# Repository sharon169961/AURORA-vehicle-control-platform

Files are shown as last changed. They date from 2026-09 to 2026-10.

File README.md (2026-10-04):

# AURORA — Autonomous Vehicle Control & Power Platform

**4-Layer Mixed-Signal PCB | TI MSPM0G3507 | DRV8323S BLDC FOC | CAN-FD | Power Management**

> Status: **Rev A** — schematic design complete, PCB layout in progress. Built in KiCad 10.



---

## Overview

AURORA is the electronics core for an autonomous ground/underwater vehicle — a single 4-layer PCB integrating power conversion, motor control, sensing, and vehicle networking. The board takes a wide-range 18–36V input and regulates it down through three cascaded stages to power an 80MHz Arm Cortex-M0+ MCU, a 3-phase BLDC gate driver with integrated current sensing, a CAN-FD vehicle network node, and a protected analog sensor front end.

This project was designed module-by-module with every component value backed by a real datasheet calculation — no placeholder values, no guessed passives.

## System Architecture

```
18–36V INPUT
      │
 [Reverse-Polarity + Transient Protection]   (LM74701-Q1, TVS-less ideal diode)
      │
      ▼
 [36V → 12V Buck]  (LM5164, synchronous, 300kHz)
      │
      ▼
 [12V → 5V Buck]   (TPS5430, 500kHz)
      │
      ▼
 [5V → 3.3V LDO]   (TLV75733)
      │
      ├──────────────┬──────────────┬──────────────┐
      ▼              ▼              ▼              ▼
   MCU CORE      ANALOG FE      CAN-FD NODE     MOTOR STAGE
 MSPM0G3507    3-ch protected   TCAN1043      DRV8323S +
 80MHz M0+     RC anti-alias   transceiver    3-phase gate
 CAN/SPI/I2C   ADC front end    120Ω term.    drive + Kelvin-
 /UART hub                                    sense shunts
```

## Key Design Decisions

- **Power tree sized from real calculations** — inductor values, feedback dividers, UVLO thresholds, and compensation networks are all calculated from TI's own design equations, not copied defaults
- **DRV8323S current sensing uses 4-pin Kelvin-sense shunts** (5mΩ, 1%) rather than 2-terminal resistors — eliminates trace/joint resistance error on the high-gain (up to 40V/V) current-sense path
- **Hardware-level motor kill switch** — a physical E-stop directly shorts the gate driver's ENABLE pin to ground, overriding any MCU/firmware state
- **TVS-less input protection** — LM74701-Q1's integrated VDS clamp meets automotive transient requirements without a discrete TVS diode
- **Reverse-polarity protection via ideal diode controller**, not a passive series diode — avoids the forward-voltage power loss of a traditional diode-OR input stage

## Schematic Highlights

| Motor Drive Stage | Power Tree | MCU Core |
|---|---|---|
| || |
| DRV8323S SPI gate driver, 6x PWM, Kelvin-sense current monitoring | 36V → 12V → 5V → 3.3V cascaded regulation, TVS-less input protection | MSPM0G3507 hub — CAN-FD, SPI, I2C, UART, SWD, 3-ch ADC |

Full schematic (all 6 sheets): [`docs/schematic-full.pdf`](docs/schematic-full.pdf)

## Tech Stack

| Domain | Parts |
|---|---|
| MCU | TI MSPM0G3507 (Arm Cortex-M0+, 80MHz, 128KB/32KB, CAN-FD, dual 12-bit ADC) |
| Motor control | TI DRV8323S (SPI-configured 3-phase gate driver, integrated current-shunt amps) |
| Power | TI LM5164, TPS5430, TLV75733, LM74701-Q1 |
| Networking | TI TCAN1043 (CAN-FD transceiver) |
| Tools | KiCad 10, Git |

## Repository Structure

```
hardware/aurora-ctrl/    KiCad project — schematic + PCB
hardware/lib/            Custom symbol/footprint libraries
hardware/outputs/        Gerbers, BOM, renders (post-fabrication)
docs/                    Architecture notes, calculations, design rationale
calcs/                   Component value derivations
```

## Status / Roadmap

- [x] Architecture + full component selection, every part datasheet-verified
- [x] Power tree (4 stages) — schematic complete, ERC clean
- [x] MCU core sheet — power, SWD, CAN, I2C/SPI/UART
- [x] Precision analog front end (3-channel, protected, anti-aliased)
- [x] 3-phase motor drive stage (DRV8323S, Kelvin-sense shunts)
- [x] CAN-FD network node
- [x] Hardware E-stop + fault indication
- [x] Whole-project schematic ERC clean, 6 sheets fully cross-wired
- [ ] PCB layout (4-layer, zoned power/analog/digital/motor)
- [ ] Gerber generation + fab
- [ ] Bring-up and validation (power rail testing, motor spin-up)

**Deferred to Rev B:** centralized PGOOD/fault-aggregation sheet, internal op-amp buffering on the analog front end (currently passive RC filtering), CAN sleep/wake modes.

---

*Designed as a demonstration of TI's embedded processing, power management, and motor control portfolio working together on a single board.*

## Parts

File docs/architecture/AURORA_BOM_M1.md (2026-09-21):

# AURORA Rev A — M1 Part Selection Lock

Every part below was verified live against TI/manufacturer data during this session.
Passive values (resistors, caps, inductors, MOSFETs, shunts) are NOT locked here —
those are calculated in M2 (power) and M5 (motor) from real design equations, not
picked in advance.

| Block | Part | Package | Key specs | Why |
|---|---|---|---|---|
| MCU | **TI MSPM0G3507SPMR** | 64-LQFP (PM) | 80MHz Cortex-M0+, 128KB flash, 32KB SRAM, 2×12-bit 4Msps ADC, 12-bit DAC, 2× zero-drift op-amp, 3× comparator, CAN-FD, hardware math accelerator | Largest package = easiest hand-solder, most GPIO/ADC breakout, native CAN-FD and analog peripherals eliminate external op-amp/ADC parts |
| CAN transceiver | **TI TCAN1042DR** | SOIC-8 | 5 Mbps, ±70V bus fault protection, 16kV HBM ESD | Catalog grade (not -Q1 automotive) — cheaper, easier to source in small qty, still robust |
| Buck stage 1 (36V→12V) | **TI LM5164DDAR** | SOIC-8 PowerPAD | 6V–100V in, 1A sync buck, constant on-time, ultra-low IQ, adjustable current limit, PGOOD, UVLO | Input range covers full 18–36V bus with margin; PowerPAD gives thermal path without needing a 4-layer thermal via array right under the IC |
| Buck stage 2 (12V→5V) | **TI TPS54331DR** | SOIC-8 | 3.5V–28V in, 3A, 570kHz current-mode, Eco-mode | 12V input is well inside its 28V max; current-mode control is simpler to compensate than COT for a first design |
| 3.3V rail | TBD in M2 | — | — | Likely a small LDO or third buck off the 5V rail — sized once the 3.3V load budget (MCU + logic) is totaled |
| Motor gate driver | **TI DRV8323SRTAR** | 40-WQFN | 6V–60V, 3× half-bridge (6 ch), integrated 3× current-shunt amps (5/10/20/40 V/V gain), SPI config, dead-time control, OTP/OVP/OCP | SPI variant chosen over PWM-only H variant so the MCU can digitally configure shunt gain and read fault status — this is the "embedded depth" the project needs |

## Deliberately deferred to later modules
- 3.3V regulator part (M2, after power budget is totaled)
- Reverse-polarity FET, TVS, fuse (M2 — sized to real fault-current calc)
- Op-amp for analog front end — **using the MSPM0's internal zero-drift op-amps** instead of an external part; simplifies BOM and is a stronger "we understood the part" story
- BLDC power MOSFETs and current-shunt resistor values (M5 — sized to real motor current)
- IMU / pressure sensor exact part numbers (M7, non-critical path)
- ESP32/LoRa module part number (M7)

## Rev A scope decision
Three-board split (Control/Power/Sensor) rejected — a single well-executed 4-layer
board is more credible in a one-day build than three partially-finished boards.

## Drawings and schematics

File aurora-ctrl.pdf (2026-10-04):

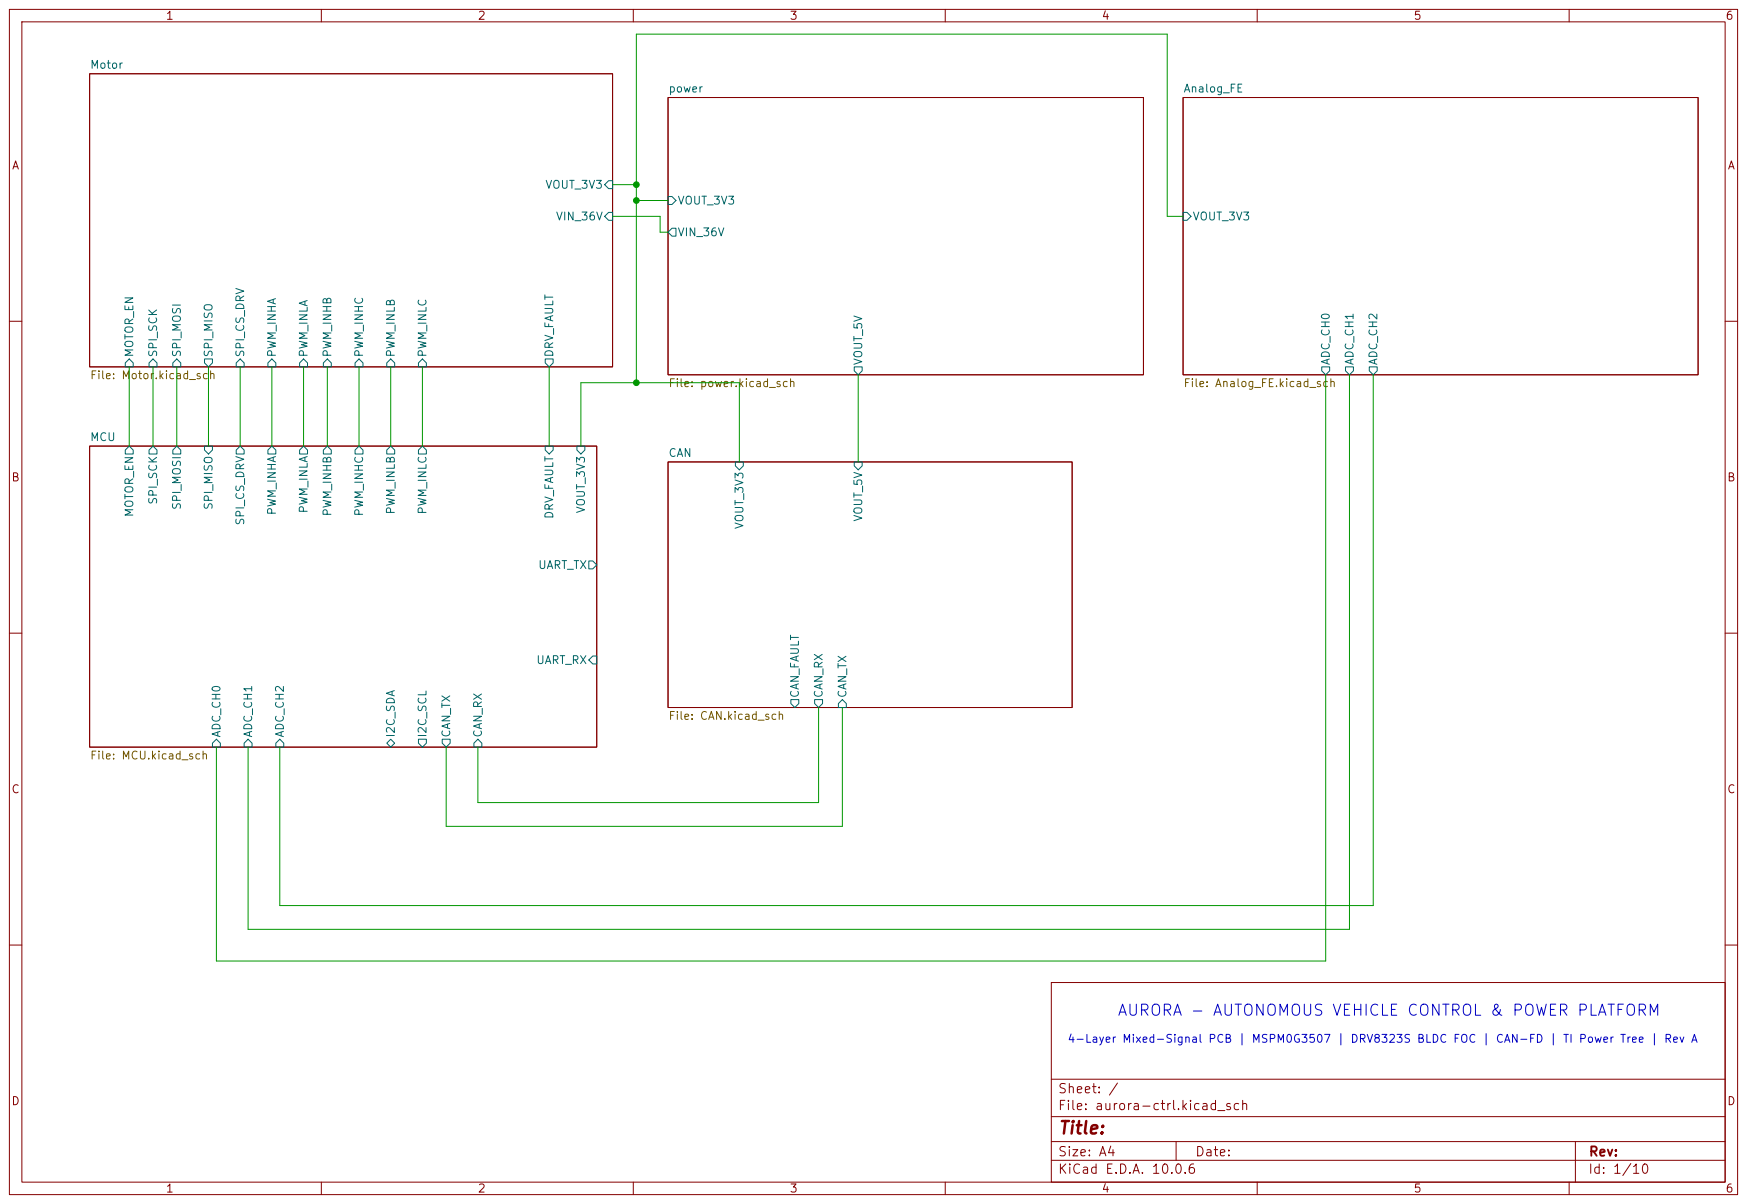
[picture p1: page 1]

AURORA - AUTONOMOUS VEHICLE CONTROL & POWER PLATFORM

4-Layer Mixed-Signal PCB | MSPM0G3507 | DRV8323S BLDC FOC | CAN-FD | TI Power Tree | Rev A

Size: A4 | Rev:
KiCad E.D.A. 10.0.6 | Id: 1/10

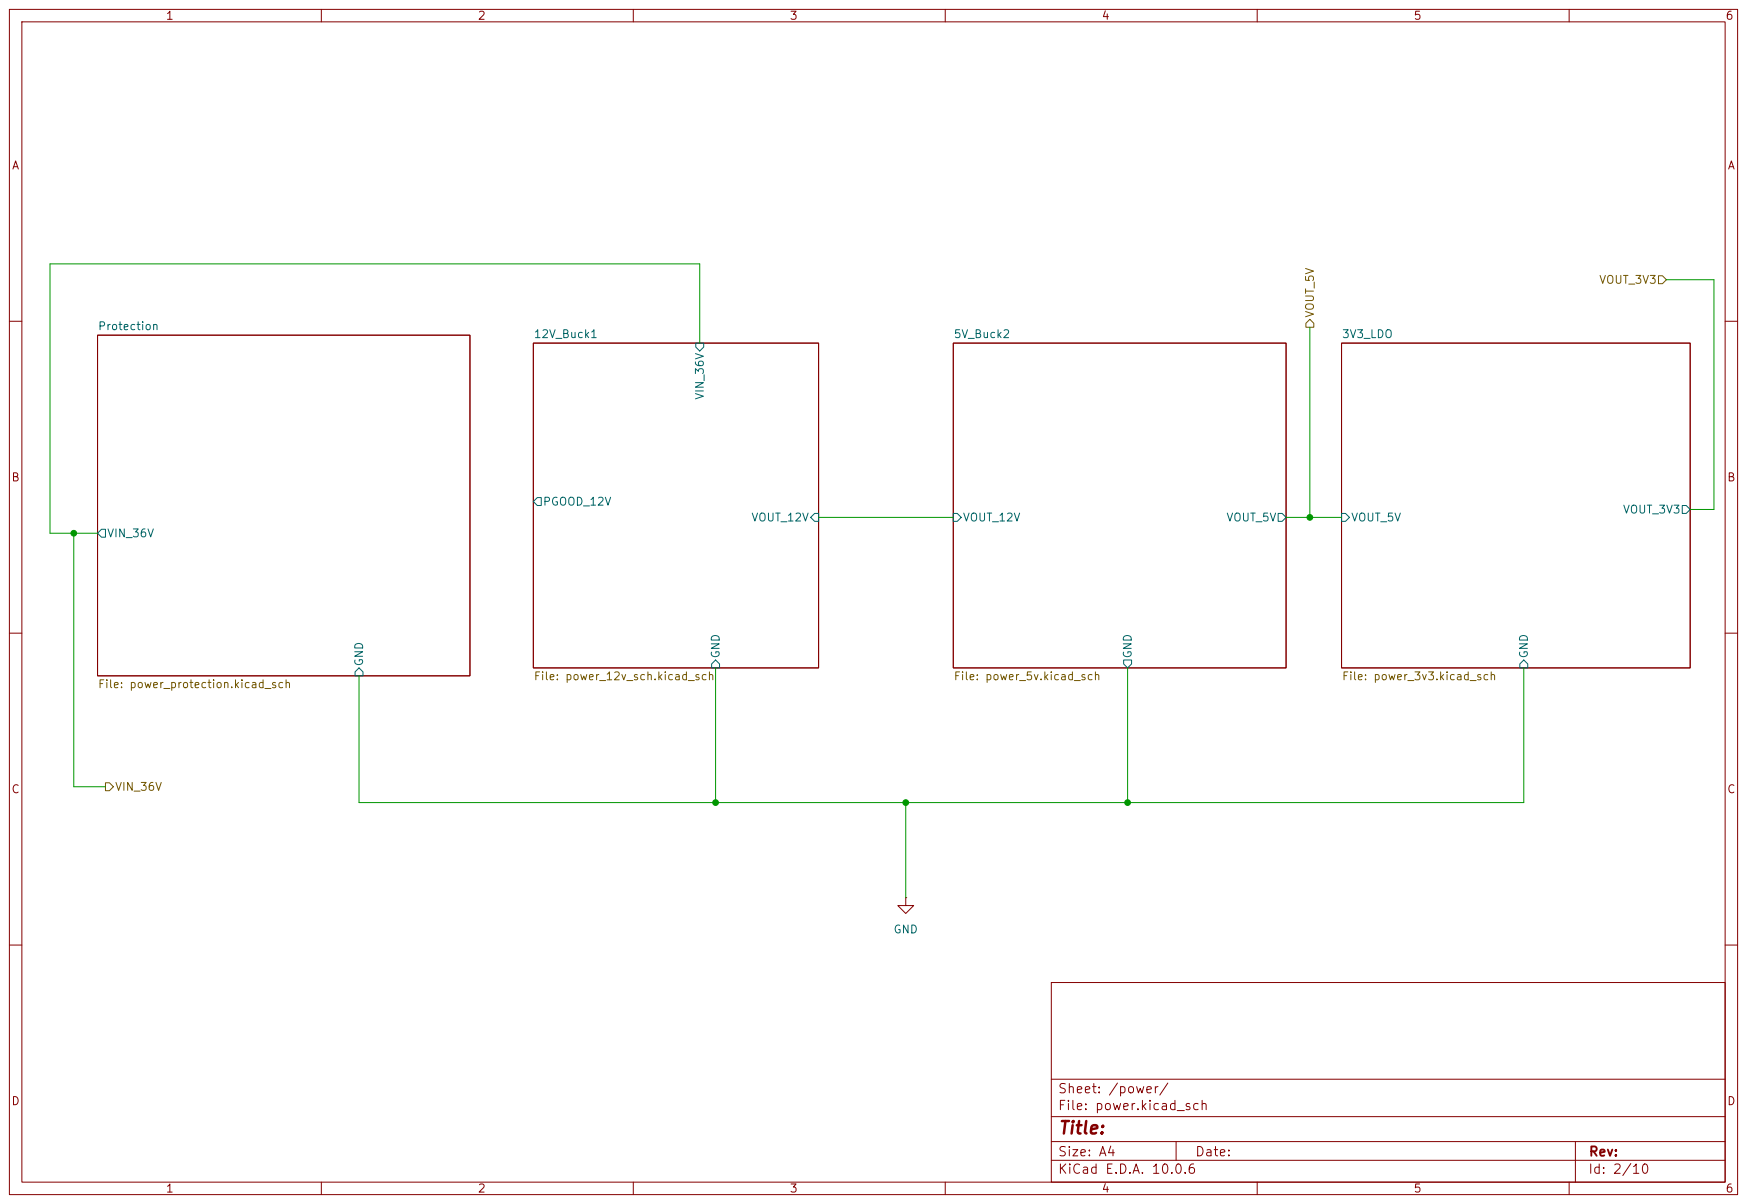
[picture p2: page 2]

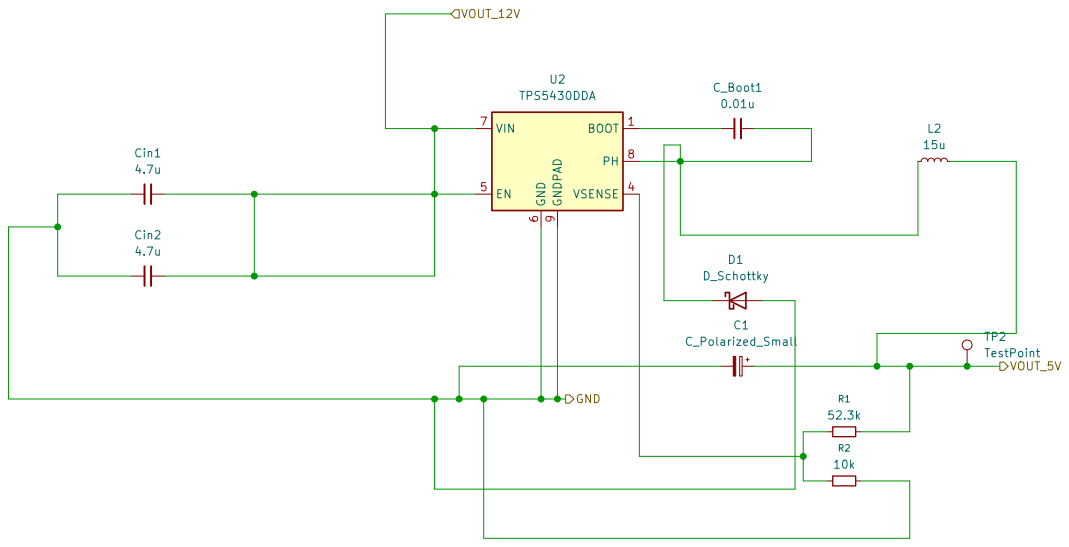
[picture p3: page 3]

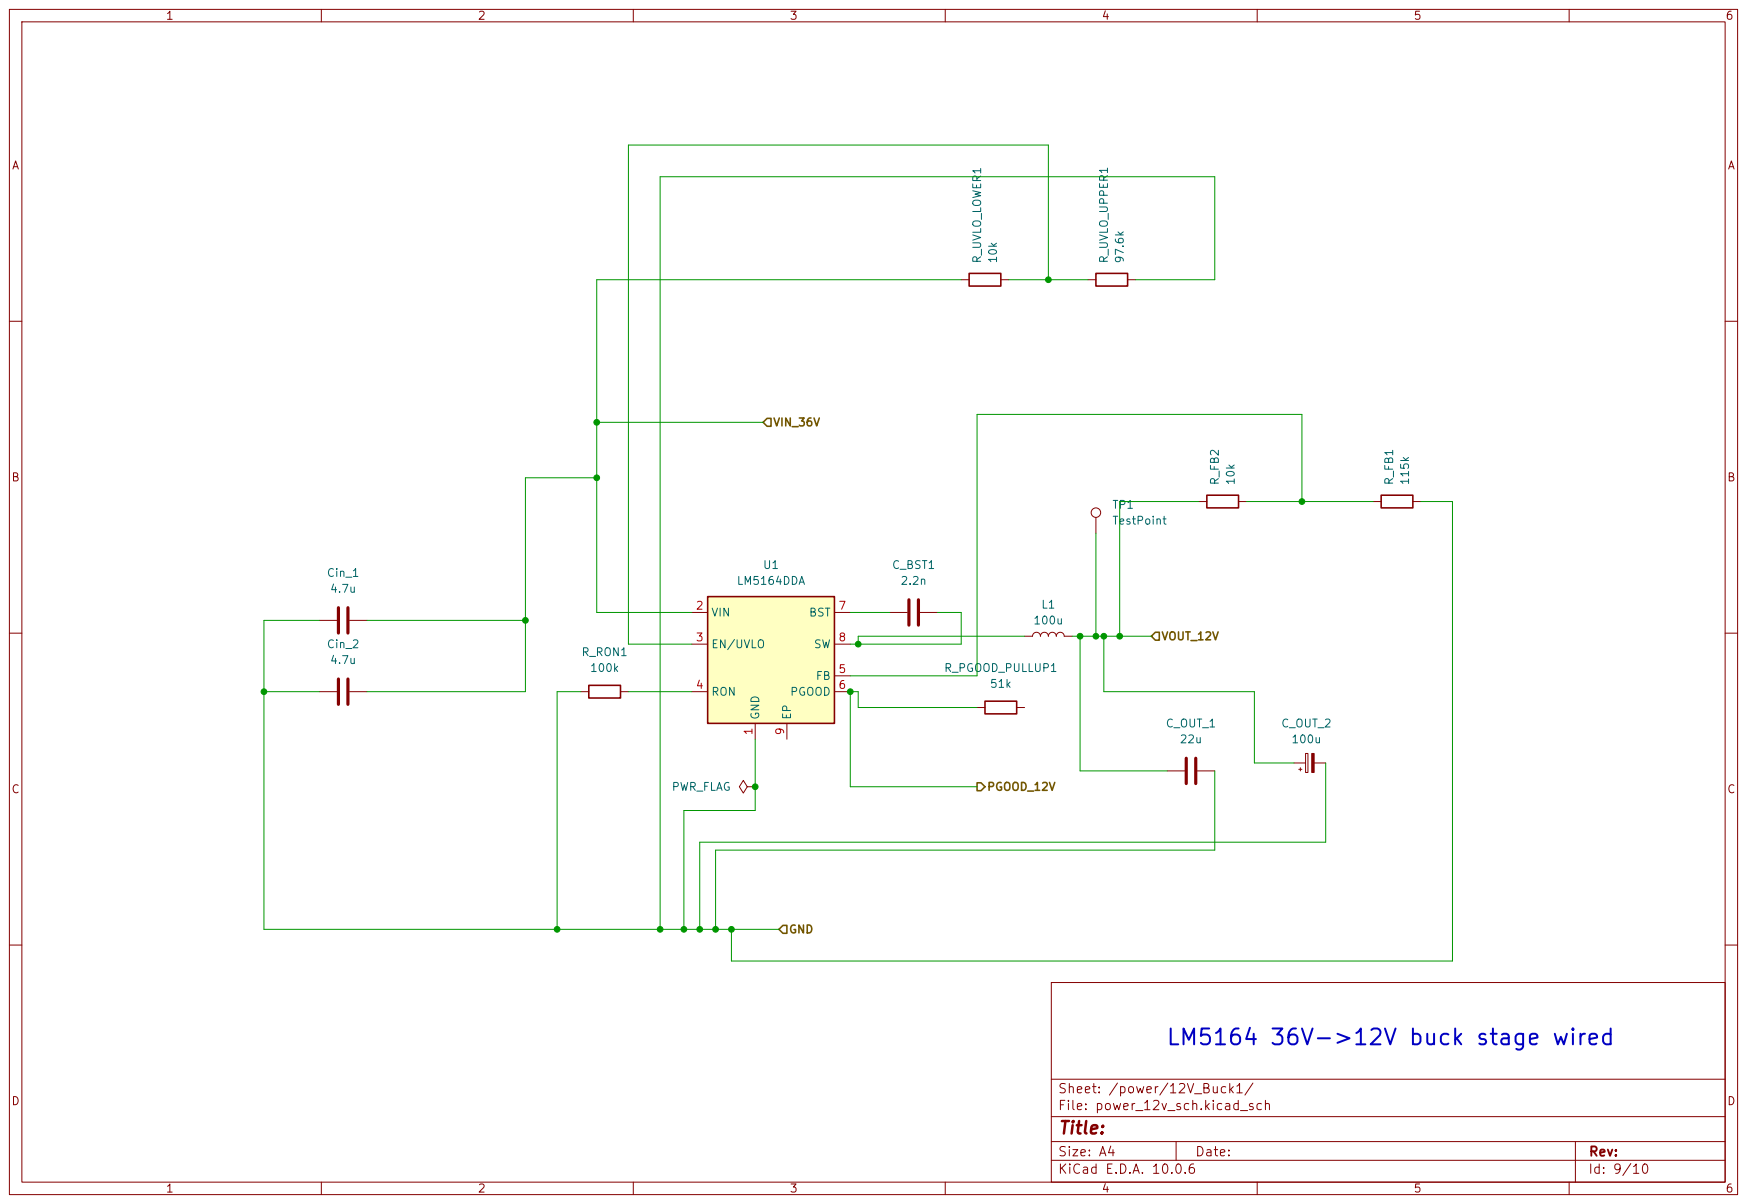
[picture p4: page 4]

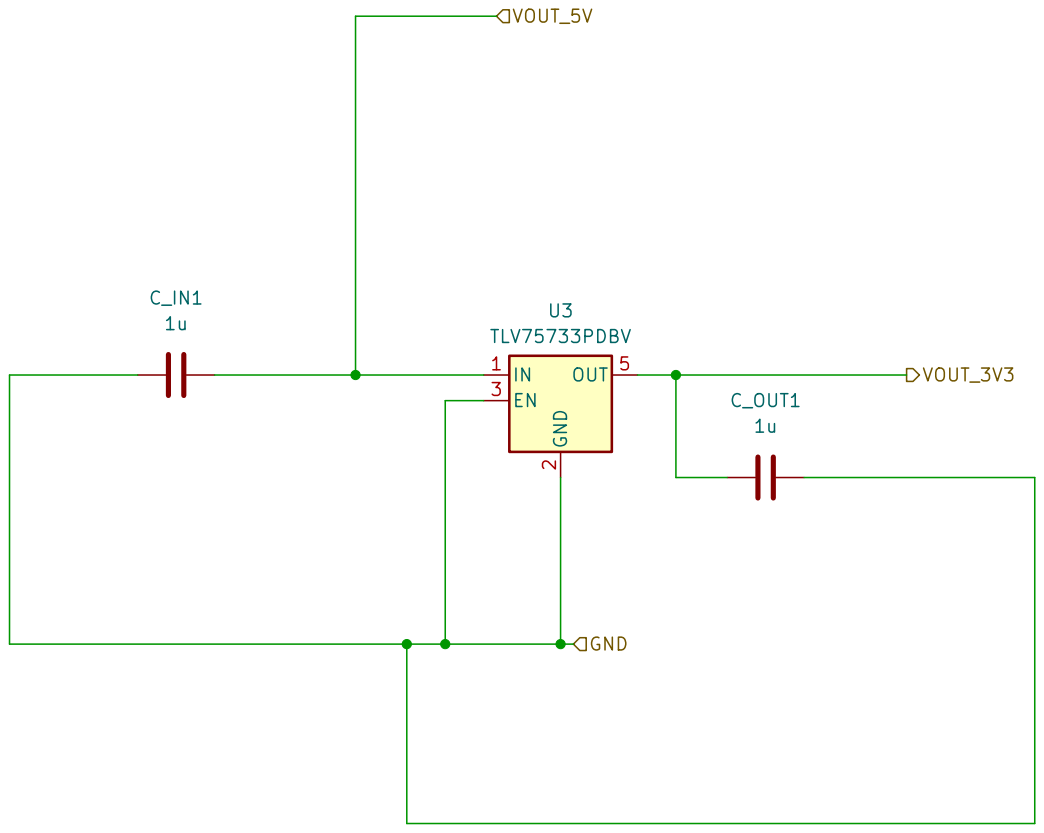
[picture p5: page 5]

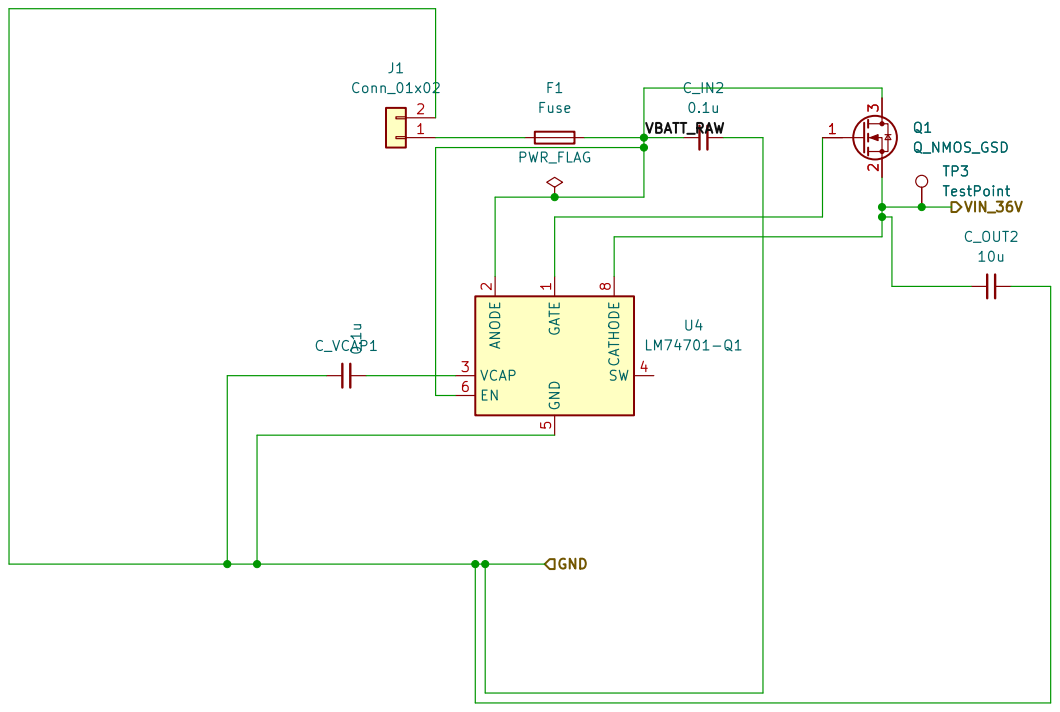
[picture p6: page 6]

POWER SATGE 0 - INPUT PROTECTION (LM4701-Q1 TVS-Less Ideal Diode)

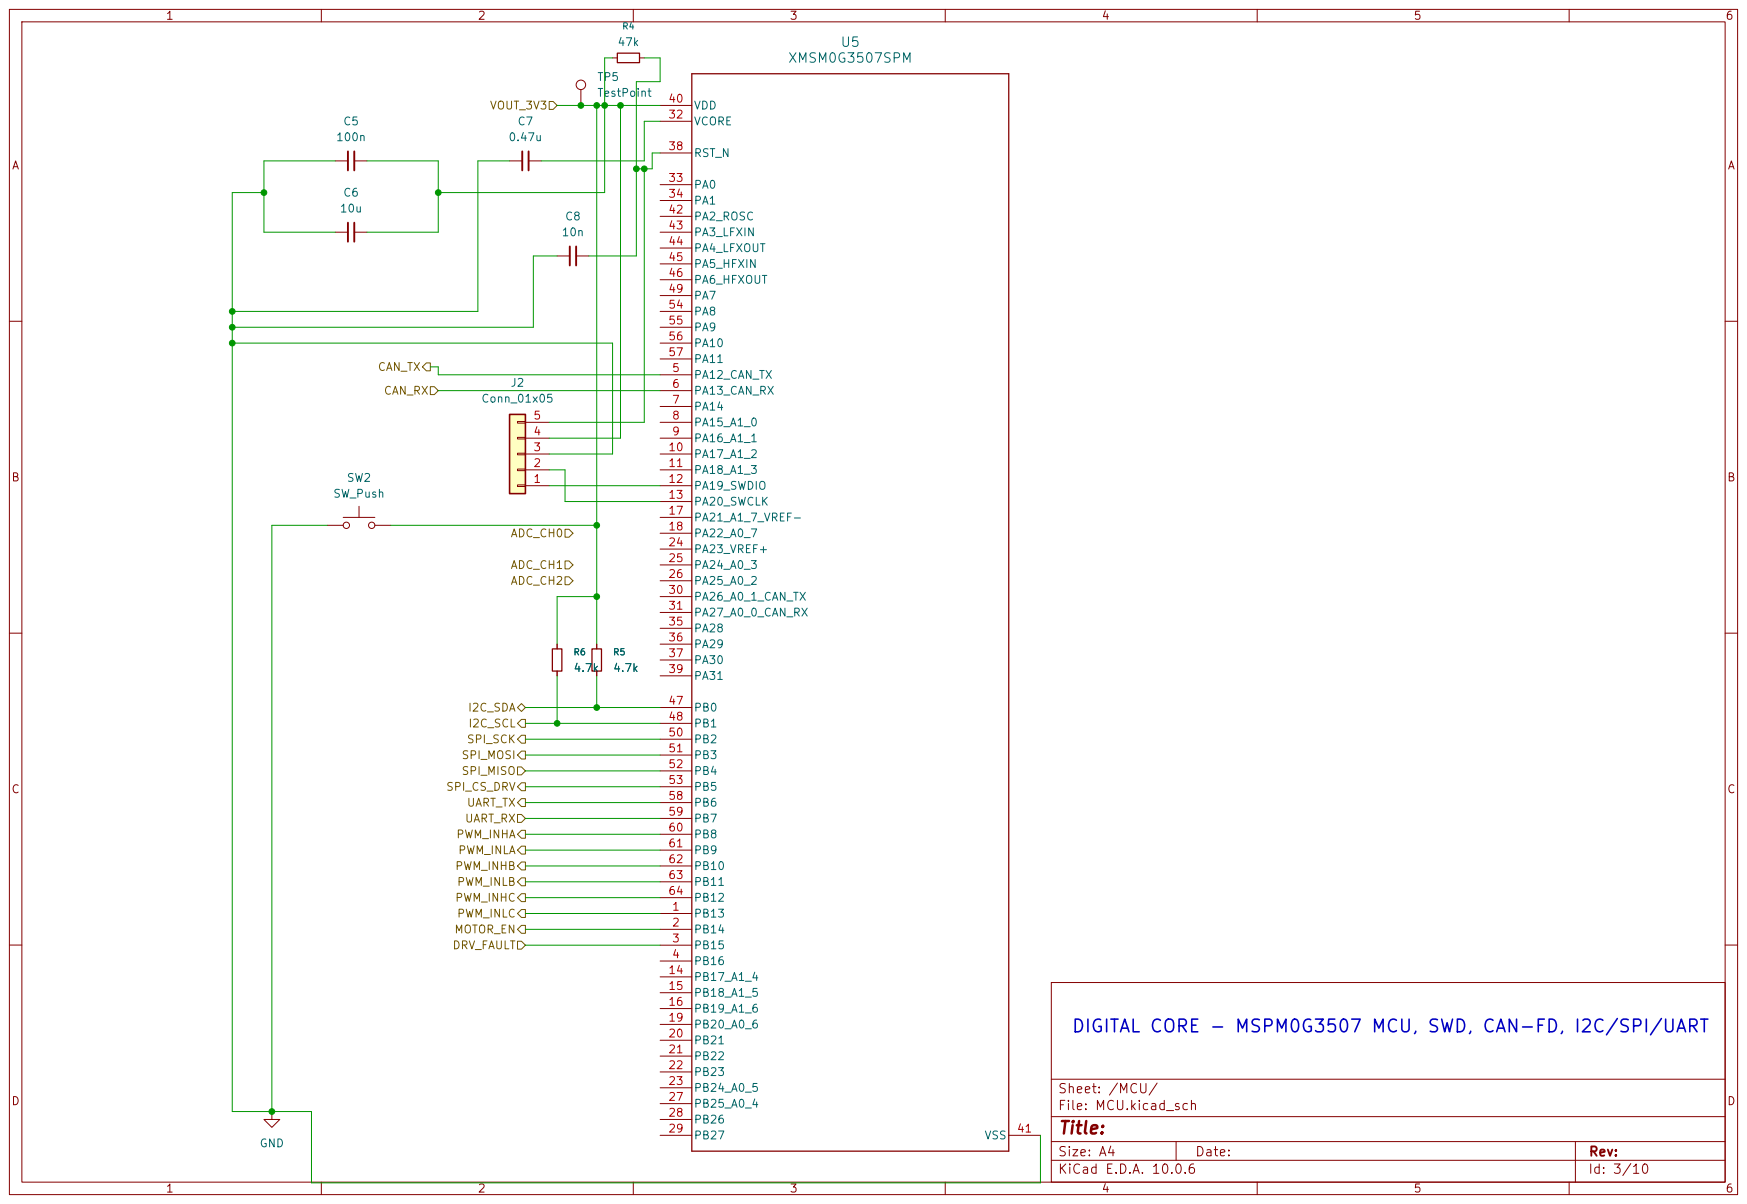
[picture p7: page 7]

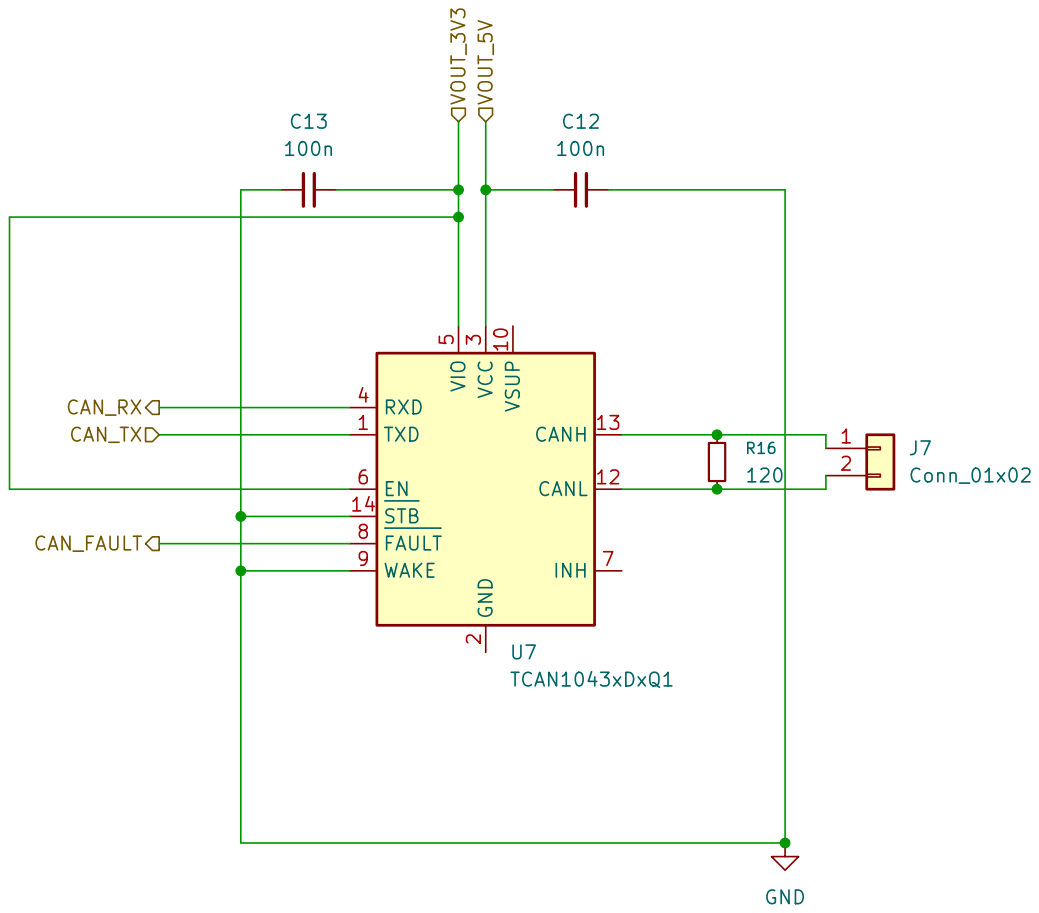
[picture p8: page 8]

CAN-FD VEHICLE NETWORK - TCAN1043 Transceiver, 120Ω Terminated Node

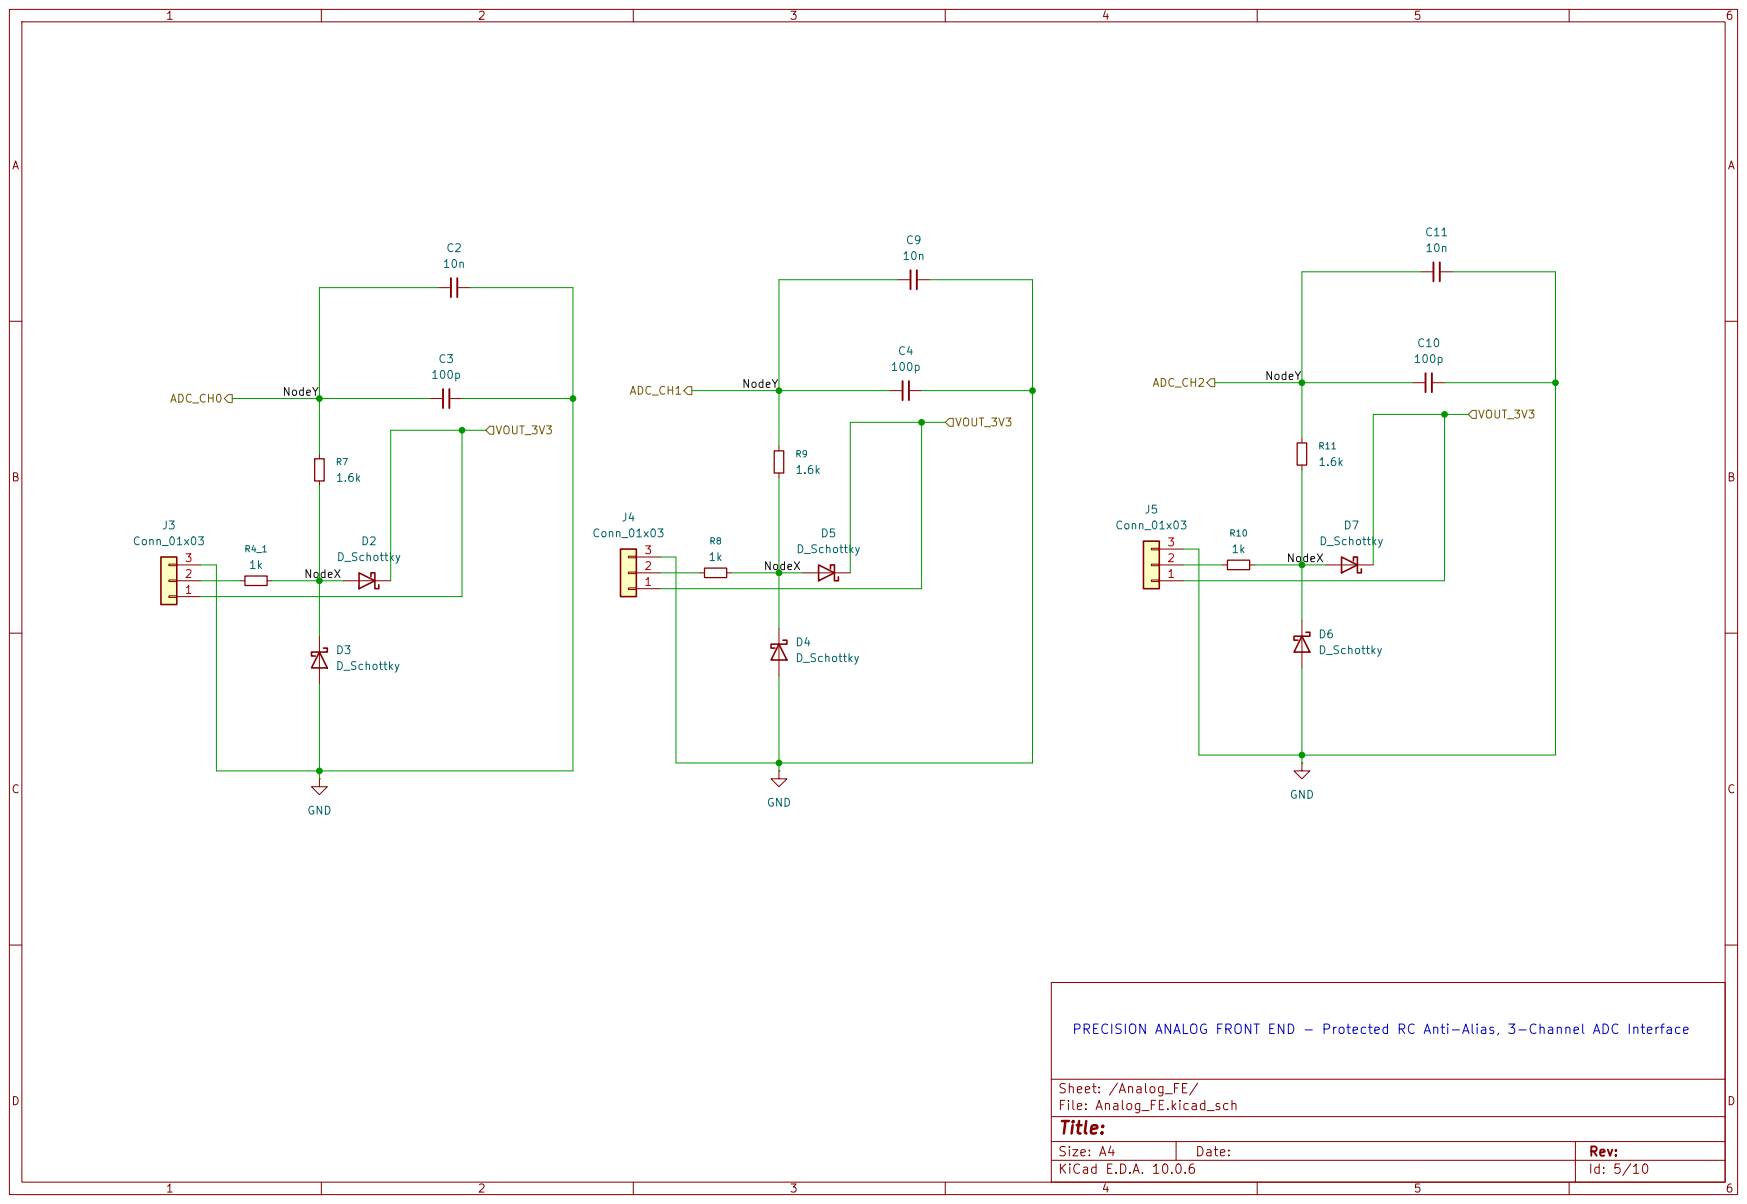
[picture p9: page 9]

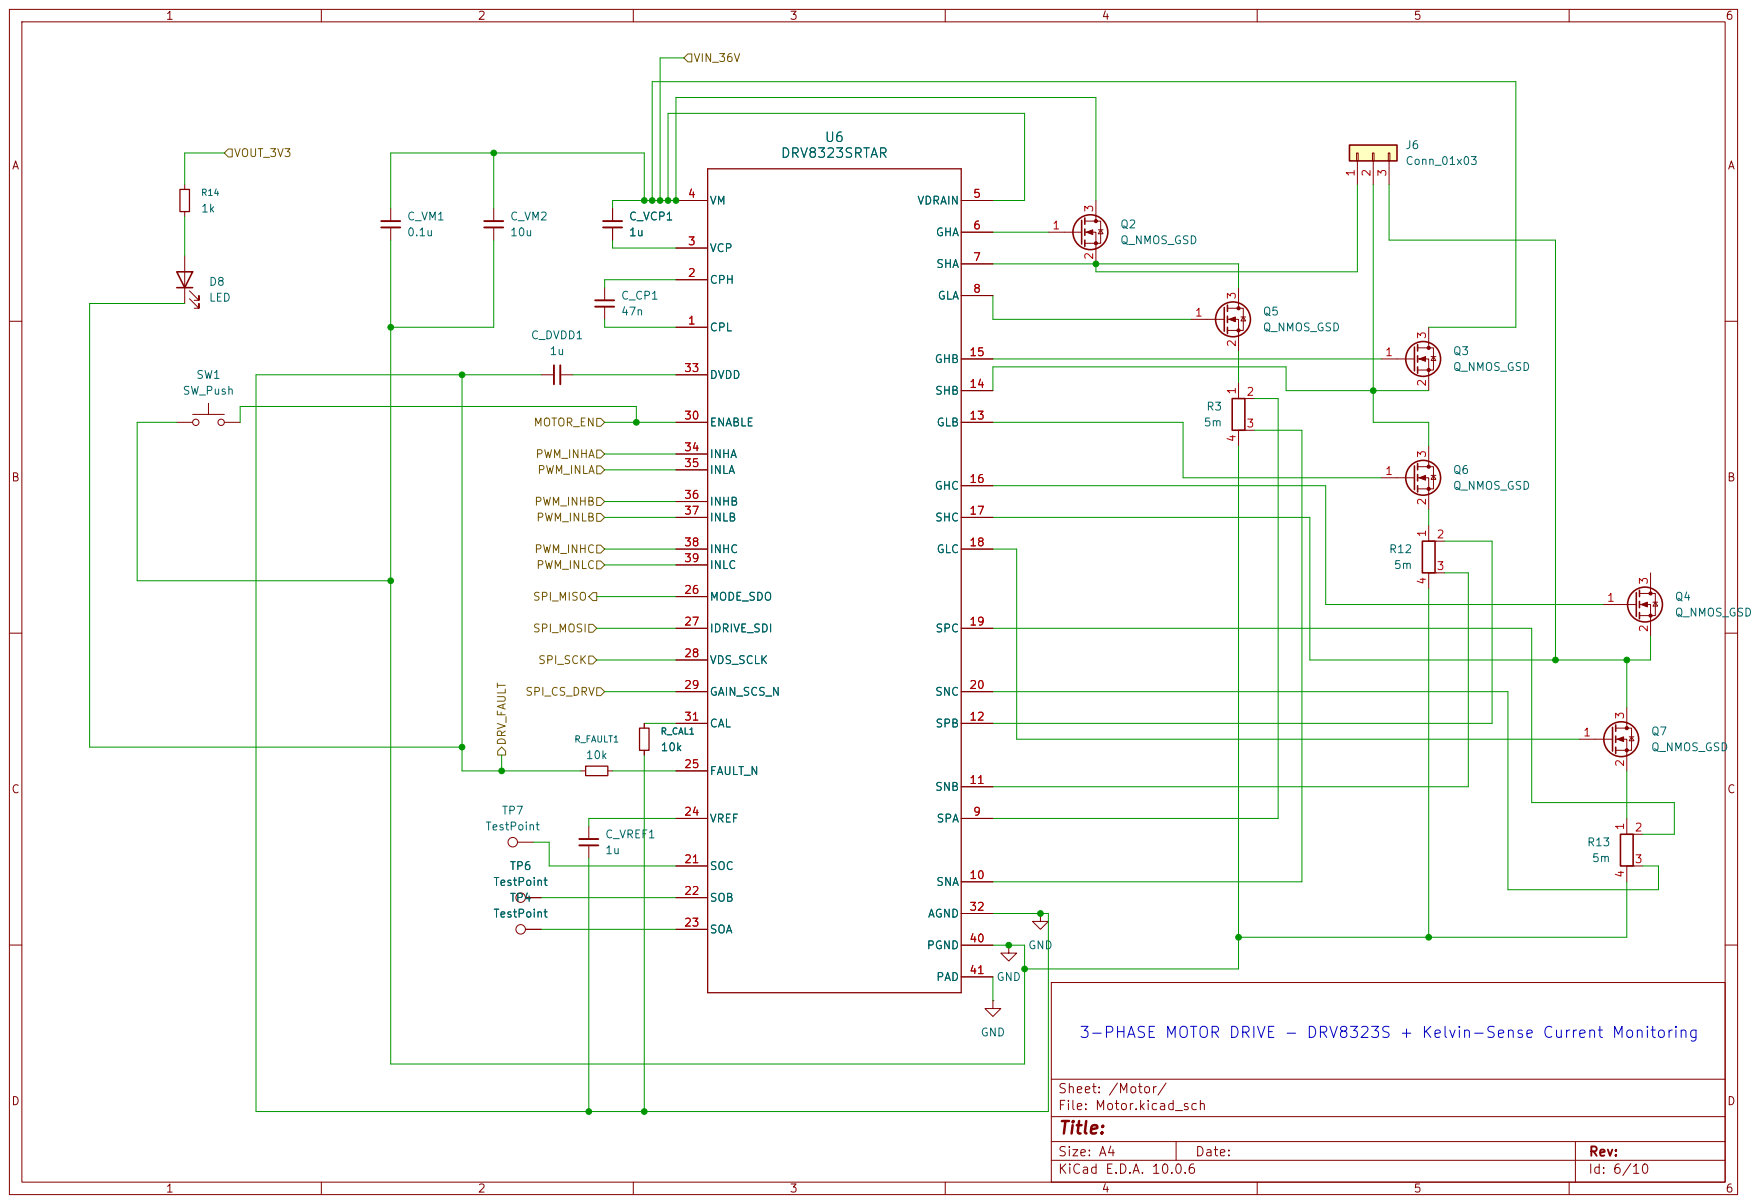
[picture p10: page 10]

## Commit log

2026-09-21 M0: project skeleton and KiCad project init
    [aurora-ctrl.kicad_pcb, aurora-ctrl.kicad_sch]
2026-09-21 M1: architecture lock and core part selection (MCU, CAN, power, gate driver)
2026-09-21 M2: LM5164 36V->12V buck stage wired, ERC clean
    [MCU.kicad_sch, power.kicad_sch]
2026-10-01 M2: TPS5430 12V->5V buck stage wired and annotated, ERC clean
    [Analog_FE.kicad_sch, CAN.kicad_sch, MCU.kicad_sch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]
2026-10-03 M2 complete: full power tree (Protection -> 12V -> 5V -> 3.3V) wired and ERC clean
2026-10-03 M3 complete: MSPM0G3507 MCU sheet wired - power, SWD, CAN, I2C, SPI, UART, ADC reserved
    [power.kicad_sch, power_12v_sch.kicad_sch, power_3v3.kicad_sch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]
2026-10-04 M5 complete: DRV8323S 3-phase motor stage wired, MCU PWM/SPI/fault labels added, full VIN_36V cross-hierarchy routing
2026-10-04 M6 complete: hardware E-stop + fault LED added, VOUT_3V3 routed to MCU/Analog_FE/Motor
2026-10-04 M7 prep: CAN sheet complete, full root-level wiring across all 6 sheets, whole-project ERC clean
